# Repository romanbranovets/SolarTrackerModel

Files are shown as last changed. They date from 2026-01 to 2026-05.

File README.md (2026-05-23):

# SolarTrackerModel

Комплексная модель двухосевого солнечного трекера в MATLAB/Simulink с сопутствующей аппаратной частью — блоком управления приводами. Проект объединяет 3D-механику на базе CAD-геометрии, модель электромеханического привода с редуктором, расчёт положения Солнца, ветровые нагрузки и оценку выработанной энергии с учётом точности наведения и потерь в приводах.

Модель собрана модульно: каждый физический аспект вынесен в отдельный `.slx`-файл и подключается в главную схему через Model Reference.

## Демонстрация

Запись симуляции из Mechanics Explorer — слежение за Солнцем, реакция на ветровую нагрузку, изменение ориентации панелей.

Симуляция работы солнечного трекера

## Структура репозитория

```
SolarTrackerModel/
├── Diplomm.m              # параметры привода, редуктора и ветровой модели
├── multibody.slx          # главная интегрированная модель
├── Actuator.slx           # электромеханический привод одной оси
├── regt.slx               # дискретный регулятор
├── MotorEnergyLoss.slx    # расчёт потерь энергии в приводе
├── SolarTrack.slx         # положение Солнца на небе
├── WindGenerator.slx      # ветровая нагрузка
├── EnergyConvert.slx      # расчёт полученной энергии
├── docs/                  # материалы для README
│   └── simulation.gif     # запись симуляции
├── Electronics/           # блок управления приводами
└── 3dmodel/               # CAD-геометрия
```

## Что реализовано

### `multibody.slx` — интегрированная модель

Центральная Simulink-модель, в которой связаны механика, управление и внешние воздействия.

- **Simscape Multibody** — трёхмерная динамика трекера с двумя степенями свободы: азимут и угол места
- **CAD-импорт** — геометрия и инерционные параметры загружаются из STEP-файлов (`3dmodel/`)
- **Два привода** — азимутальный и по углу места, каждый через `Actuator.slx`
- **Внешние воздействия** — солнечная траектория (`SolarTrack.slx`) и ветер (`WindGenerator.slx`)
- **Энергетический баланс** — интеграл полезной выработки с вычетом потерь приводов (`EnergyConvert.slx`)
- **Режимы работы** — автоматическое слежение за Солнцем и ручная подача уставок через переключатели
- **Визуализация** — Scope для углов ориентации и накопленной энергии

Решатель: `ode45`, время моделирования 0–250 с.

### `Actuator.slx` — электромеханический привод

Модель одной оси вращения. Используется дважды — для азимута и угла места.

- **Контур управления** — ошибка по углу, масштабирование и дискретный регулятор `regt.slx` (Ts = 0.01 с)
- **Модель ДПТ** — RL-цепь обмотки, ограничения по напряжению (±24 В) и току (±6.5 А), мёртвая зона «напряжения трогания» (±1.2 В), противо-ЭДС
- **Редуктор** (i = 619) — люфт (dead zone), нелинейное трение, MATLAB Function для определения контакта в зазоре
- **Обратная связь** — угол и скорость с механической части; внешний момент от ветра на входе
- **Выходы** — крутящий момент на шарнир Simscape, напряжение и ток для расчёта потерь

### `regt.slx` — дискретный регулятор

Дискретный компенсатор с периодом дискретизации 0.01 с. Структура — каскад блоков задержки и усиления, полученный в результате дискретизации непрерывной передаточной функции (см. закомментированный код синтеза в `Diplomm.m`).

### `SolarTrack.slx` — положение Солнца

Расчёт углов Солнца для заданного места наблюдения (широта 55°, долгота 37°, часовой пояс UTC+3).

- Склонение Солнца по номеру дня года
- Уравнение времени
- Часовой угол, зенитный угол, высота и азимут
- Ограничение видимости — обнуление угла, когда Солнце ниже горизонта

### `WindGenerator.slx` — ветровая нагрузка

Модель аэродинамического давления на солнечные панели.

- **Скорость ветра** — средняя составляющая, порывы и шум; ограничение 0–25 м/с
- **Направление** — медленные колебания по азимуту и углу места
- **Сила** — пропорциональна квадрату скорости ветра и косинусу угла между ориентацией панели и направлением потока; учитываются габариты панелей (`laz`, `lel`)
- **Выходы** — моменты `MvAz`, `MvEl`, подаваемые на соответствующие приводы

Профиль ветра задокументирован в чертеже `3dmodel/w(t).cdw`.

### `EnergyConvert.slx` — выработанная энергия

Оценка полезной энергии с учётом качества наведения.

- Ошибки ориентации относительно солнечных уставок: `epsAz`, `epsEl`
- КПД наведения: `cos(epsAz) × cos(epsEl)` с пороговым отсечением при больших ошибках
- Номинальная мощность панелей — 400 Вт
- Модель затенения (импульсное снижение освещённости)
- Интеграл: полезная энергия минус потери обоих приводов (`MotorEnergyLoss.slx`)

### `MotorEnergyLoss.slx` — потери в приводе

Расчёт энергозатрат на ориентацию: интеграл `|U · I|` по напряжению и току двигателя.

### `Diplomm.m` — параметры системы

Скрипт инициализации, загружающий в workspace параметры электродвигателя, редуктора и ветровой модели:

| Группа | Параметры |
|---|---|
| Двигатель | `R`, `L`, `Km`, `Kw`, `J`, `Jd` |
| Редуктор | `i`, `c`, `a`, `b`, параметры трения `F1`, `F2`, `G1`, `G2`, `G` |
| Регулятор | `KPDr` |
| Ветер | `laz`, `lel` — характерные размеры панелей |

### `3dmodel/` — CAD-геометрия

Трёхмерная модель механической части трекера.

Основные компоненты: основание, азимутальная рама, солнечные панели, вал, корпус мотора. Сборки включают конфигурации с углом места 0° и 90°.

### `Electronics/` — блок управления

Аппаратная часть системы управления — печатная плата **«Блок управления»** для двухканального управления приводами трекера. Разработка выполнена в Altium Designer; комплект конструкторской документации оформлен по ЕСКД.

**Исходные файлы:**

| Файл | Назначение |
|---|---|
| `main.SchDoc` | принципиальная электрическая схема |
| `PCBGOST.PcbDoc` | топология печатной платы (200×200 мм) |

**Документация (PDF):**

| Файл | Назначение |
|---|---|
| `СхемаЭ3.pdf` | схема электрическая принципиальная (форма Э3) |
| `ПЭ3.pdf` | перечень элементов с пояснениями |
| `Спецификация.pdf` | спецификация на блок управления |
| `СБПДФ.pdf` | сборочный чертёж платы |
| `плата.pdf` | чертёж печатной платы |

**Что реализовано на схеме:**

- **Микроконтроллер STM32F205RGT6** — формирование ШИМ-сигналов управления, UART-интерфейс, опрос датчиков; тактирование от кварца 8 МГц
- **Два силовых канала** — независимое управление приводами азимута и угла места; каждый канал построен на 6 MOSFET-транзисторах `IRFR7740` в трёхполумостовой конфигурации с драйверами `IRS2011`
- **Гальваническая развязка** — 12 оптронов `249ЛП5` в цепях управления затворами; линейные оптопары `IL300` в каналах измерения тока
- **Измерение тока двигателей** — шунты 0.2 Ом, усиление на `LM2904`, гальванически развязанная передача сигналов `I1`/`I2` на АЦП микроконтроллера
- **Система питания** — вход 24 В (разъём `XT30`); DC-DC-преобразователи на шины +15 В, +5 В, +3.3 В для силовой и логической частей
- **Разъёмы** — силовой ввод, UART, JTAG/SWD для отладки, 4 клеммных разъёма Molex для подключения двигателей и периферии

Плата связана с Simulink-моделью через параметры привода из `Diplomm.m` (сопротивление обмотки, ограничения по напряжению и току, передаточное число редуктора) — модель отражает те же электромеханические характеристики, что заложены в аппаратную часть.

## Связи между модулями

```mermaid
flowchart LR
    subgraph Окружение
        ST[SolarTrack]
        WG[WindGenerator]
    end

    subgraph Управление
        ACT[Actuator]
        REG[regt]
        MEL[MotorEnergyLoss]
    end

    subgraph Механика
        MB[multibody]
    end

    subgraph Энергетика
        EC[EnergyConvert]
    end

    ST -->|уставки| ACT
    ST --> EC
    WG -->|моменты| ACT
    ACT --> REG
    ACT -->|момент| MB
    ACT --> MEL
    MB -->|углы, скорости| ACT
    MB -->|углы| WG
    MB -->|углы| EC
    MEL -->|потери| EC
    EC -->|энергия| MB
```

**Поток сигналов:**

1. `SolarTrack` формирует уставки азимута и угла места → `Actuator` (через переключатели режима)
2. `Actuator` выдаёт момент → шарниры Simscape Multibody → углы и скорости обратно в привод
3. `WindGenerator` получает текущую ориентацию и генерирует моменты нагрузки → `Actuator`
4. Углы, солнечные уставки и потери приводов → `EnergyConvert` → интеграл выработанной энергии

## Запуск

**Требования:** MATLAB R2025a (или совместимая версия) с Simulink, Simscape, Simscape Multibody.

1. Открыть проект в MATLAB
2. Выполнить `Diplomm.m` — загрузка параметров в workspace
3. Открыть `multibody.slx` и запустить симуляцию
4. Убедиться, что все Model Reference и STEP-файлы из `3dmodel/` доступны по относительным путям

## Инструменты

| Категория | Инструменты |
|---|---|
| Моделирование | MATLAB / Simulink, Simscape, Simscape Multibody |
| Управление | Дискретный компенсатор, ZOH-дискретизация |
| CAD | SolidWorks, KOMPAS-3D |
| Схемотехника | Altium Designer |

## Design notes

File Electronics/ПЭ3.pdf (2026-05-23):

Изм | Лист | № докум. | Подп. | Дата Инв. № подл. Подп. и дата Инв. № дубл. Взам. инв. № Подп. и дата Перв. Примен. Справ. №
| | | СМ7.000001.001ПЭ3
Разраб. | Брановец | Блок управления Перечень элементов | Лит. | Лист | Листов
Пров. | Романова-Большакова | | | | | 1 5

МГТУ им. Н.Э. Баумана

Поз. обозначен ие | Наименование | Кол. | Примечание
| КОНДЕНСАТОРЫ
С1-C8 | CC0402JRX7R7BB104-0,1мкФ ±15% -16В | 8 | Типоразмер 0402
С9-C10 | CL21B225KAFNNNE-2,2мкФ±15%-25В | 2 | Типоразмер 0805
С11 | CC0603JRNPO8BN150-15пФ±5%-25В | 1 | Типоразмер 0603
С12-С15 | CC0402JRX7R7BB104-0,1мкФ ±15% -16В | 4 | Типоразмер 0402
С16 | EEEFK1H101P-100мкФ±20%-50В | 1
С17 | EEEFK1E220R-22мкФ±20%-25В | 1
С18 | CC0603JRNPO8BN150-15пФ±5%-25В | 1 | Типоразмер 0603
С19 | CL10B104KB8NNNC-0,1мкФ±15% -50В | 1 | Типоразмер 0603
С20 | EEEFK1H101P-100мкФ±20%-50В | 1
С21 | EEEFK1E220R-22мкФ±20%-25В | 1
С22-С27 | CC0402JRX7R7BB104-0,1мкФ ±15% -16В | 6 | Типоразмер 0402
С28-С30 | CL10B104KB8NNNC-0,1мкФ±15% -50В | 3 | Типоразмер 0603
С31-С34 | EEEFK1K220P-22мкФ±20% -80В | 4
С35 | CL10B104KB8NNNC-0,1мкФ±15% -50В | 1 | Типоразмер 0603
С36 | CC0402JRX7R7BB104-0,1мкФ ±15% -16В | 1 | Типоразмер 0402
С37-С39 | CL10B104KB8NNNC-0,1мкФ±15% -50В | 3 | Типоразмер 0603
С40 | CC0402JRX7R7BB104-0,1мкФ ±15% -16В | 1 | Типоразмер 0402
С41 | CL10B104KB8NNNC-0,1мкФ±15% -50В | 1 | Типоразмер 0603
С42 | CL32B225KCJSNNE-2,2мкФ±15%-100В | 1 | Типоразмер 1210
С43-С44 | CC0402JRX7R7BB104-0,1мкФ ±15% -16В | 2 | Типоразмер 0402
С45 | CL10B104KB8NNNC-0,1мкФ±15% -50В | 1 | Типоразмер 0603
С46 | CC0402JRX7R7BB104-0,1мкФ ±15% -16В | 1 | Типоразмер 0402
С47 | CL32B225KCJSNNE-2,2мкФ±15%-100В | 1 | Типоразмер 1210
С48 | CL10B104KB8NNNC-0,1мкФ±15% -50В | 1 | Типоразмер 0603
С49 | CC0402JRX7R7BB104-0,1мкФ ±15% -16В | 1 | Типоразмер 0402

СМ7.000001.001ПЭ3
2

Лист Инв. № подл.

С50-С53 | CL10B104KB8NNNC-0,1мкФ±15% -50В | 4 | Типоразмер 0603
С54-С55 | CC0402JRX7R7BB104-0,1мкФ ±15% -16В | 2 | Типоразмер 0402

МИКРОСХЕМЫ

DA1 | UWF1205S-3WR3 | 1 | DC-DC преобразователь
DA2 | IRS2011SPbf | 1 | Драйвер полумоста
DA3 | UWF1205S-3WR3 | 1 | DC-DC преобразователь
DA4-DA6 | SN74LVC2G17 | 3 | Буфер
DA7 | AM2S-2415SZ | 1 | DC-DC преобразователь
DA8-DA11 | SN74LVC2G17 | 4 | Буфер
DA12 | AM2S-2403SZ | 1 | DC-DC преобразователь
DA13 | IRS2011SPbf | 1 | Драйвер полумоста
DA14 | SN74LVC2G17 | 1 | DC-DC преобразователь
DA15 | IL300 | 1 | Линейная оптопара
DA16 | IRS2011SPbf | 1 | Драйвер полумоста
DA17 | LM2904DR2G | 1 | Операционный усилитель
| | DA18 | SN74LVC2G17 | 1 | Буфер
| | DA19 | IL300 | 1 | Линейная оптопара
| | DA20 | SN74LVC2G17 | 1 | Буфер
| | DA21 | IL300 | 1 | Линейная оптопара
| | DA22 | LM2904DR2G | 1 | Операционный усилитель
| | DA23 | IRS2011SPbf | 1 | Драйвер полумоста
| | DA24 | SN74LVC2G17 | 1 | Буфер
| | Изм Лист DA25 | № докум. Подп. Дата Подп. и дата Взам. инв.№ Инв. № дубл. Подп. и дата IL300 | 1 | Линейная оптопара
| | DA26 | LM2904DR2G | 1 | Операционный усилитель
| | DA27 | SN74LVC2G17 | 1 | Буфер
| | DA28- | IRS2011SPbf | 2 | Драйвер полумоста
| | DA29
| | DA30- | SN74LVC2G17 | 2 | Драйвер полумоста
| | DA31
| | DD1-DD8 | 249ЛП5 | 8 | Оптрон
| | DD9 | STM32F205RGT6 | 1 | Микроконтроллер
| | DD10-DD13 | 249ЛП5 | 4 | Оптрон

3

Резисторы Р1-12 | ШКАБ.434110.002 ТУ
R1-R4 | Р1-12-0,125-340 Ом ±1% - М | 4
R5-R8 | Р1-12-0,125-169 Ом ±1% - М | 4
R9-R11 | Р1-12-0,062-20 кОм ±5% - М | 3
R12-R15 | Р1-12-0,125-340 Ом ±1% - М | 4
R16-R17 | Р1-12-0,062-20 кОм ±5% - М | 2
R18-R21 | Р1-12-0,125-169 Ом ±1% - М | 4
R22-R26 | Р1-12-0,062-20 кОм ±5% - М | 5
R27-R30 | Р1-12-0,125-340 Ом ±1% - М | 4
R31 | Р1-12-0,062-20 кОм ±5% - М | 1
R32-R35 | Р1-12-0,125-169 Ом ±1% - М | 4
R36 | Р1-12-0,062-20 кОм ±5% - М | 1
R37 | Р1-12-0,062-680 Ом ±1% - М | 1
R38 | Р1-12-0,125-10 кОм ±5% - М | 1
R39 | Р1-12-0,062-10 кОм ±5% - М | 1
R40-R41 | Р1-12-0,125-15 Ом ±1% - М | 2
| | R42 | Р1-12-0,125-10 кОм ±5% - М | 1
| | R43-R44 | Р1-12-0,062-10 кОм ±5% - М | 2
| | R45 | Р1-12-0,125-10 кОм ±5% - М | 1
| | R46-R47 | Р1-12-0,125-15 Ом ±1% - М | 2
| | R48-R49 | Р1-12-0,125-10 кОм ±5% - М | 2
| | R50 | Р1-12-0,062-1.2 кОм ±1% - М | 1
| | R51 | Р1-12-0,125-15 Ом ±1% - М | 1
| | Изм Лист R52 | № докум. Подп. Дата Подп. и дата Взам. инв.№ Инв. № дубл. Подп. и дата Р1-12-0,062-20 кОм ±5% - М | 1
| | R53 | Р1-12-0,125-15 Ом ±1% - М | 1
| | R54 | Р1-12-0,062-47 кОм ±1% - М | 1
| | R55 | Р1-12-0,062-20 кОм ±5% - М | 1
| | R56 | Р1-12-0,125-10 кОм ±5% - М | 1
| | R57 | Р1-12-0,062-1.2 кОм ±1% - М | 1
| | R58 | Р1-12-0,062-20 кОм ±5% - М | 1
| | R59-R62 | WSR3R2000FEA-3Вт-0,2 Ом ±1% | 4
| | R63 | Р1-12-0,062-47 кОм ±1% - М | 1
| | R64 | Р1-12-0,062-20 кОм ±5% - М | 1

4

R65 | Р1-12-0,062-620 кОм ±5% - М | 1
R66 | Р1-12-0,125-10 кОм ±5% - М | 1
R67 | Р1-12-0,062-1.2 кОм ±1% - М | 1
R68 | Р1-12-0,125-15 Ом ±1% - М | 1
R69-R70 | Р1-12-0,062-20 кОм ±5% - М | 2
R71 | Р1-12-0,125-15 Ом ±1% - М | 1
R72 | Р1-12-0,062-47 кОм ±1% - М | 1
R73 | Р1-12-0,125-10 кОм ±5% - М | 1
R74 | Р1-12-0,062-620 кОм ±5% - М | 1
R75 | Р1-12-0,062-1.2 кОм ±1% - М | 1
R76 | Р1-12-0,062-20 кОм ±5% - М | 1
R77 | Р1-12-0,062-47 кОм ±1% - М | 1
R78 | Р1-12-0,062-20 кОм ±5% - М | 1
R79 | Р1-12-0,125-10 кОм ±5% - М | 1
R80 | Р1-12-0,062-18 кОм ±1% - М | 1
R81 | Р1-12-0,125-15 Ом ±1% - М | 1
R82 | Р1-12-0,062-10 кОм ±5% - М | 1
| | R83 | Р1-12-0,125-95,3 Ом ±1% - М | 1
| | R84-R87 | WSR3R2000FEA-3Вт-0,2 Ом ±1% - М | 4
| | R88 | Р1-12-0,125-15 Ом ±1% - М | 1
| | R89 | Р1-12-0,125-95,3 Ом ±1% - М | 1
| | R90 | Р1-12-0,125-95,3 Ом ±1% - М | 1
| | R91 | Р1-12-0,125-10 кОм ±5% - М | 1
| | R92 | Р1-12-0,062-18 кОм ±1% - М | 1
| | Изм Лист R93 | № докум. Подп. Дата Подп. и дата Взам. инв.№ Инв. № дубл. Подп. и дата Р1-12-0,125-95,3 Ом ±1% - М | 1
| | R94 | Р1-12-0,062-10 кОм ±5% - М | 1
| | R95-R96 | Р1-12-0,125-95,3 Ом ±1% - М | 2
| | R97 | Р1-12-0,062-1 кОм ±5% - М | 1
| | R98 | Р1-12-0,125-10 кОм ±5% - М | 1
| | R99 | Р1-12-0,062-1 кОм ±5% - М | 1
| | R100 | Р1-12-0,125-15 Ом ±1% - М | 1
| | R101 | Р1-12-0,062-1 кОм ±5% - М | 1
| | R102 | Р1-12-0,125-15 Ом ±1% - М | 1
| | R103 | Р1-12-0,125-10 кОм ±5% - М | 1

5

ДИОДЫ

VD1-VD2 | DFLS160-7-60В-1А | 2
VD3-VD4 | VS-8TQ100S-M3-100В-8А | 2
VD5-VD8 | DFLS160-7-60В-1А | 4

ТРАНЗИСТОРЫ

VT1- | IRFR7740PbF-75В-87А | 12
VT12

ДРОССЕЛИ

L1-L2 | IHLP-6767GZ-01-15мкГн±30%-25А | 2
L3-L8 | IHLP-6767GZ-11-100мкГн±30%-10А | 6

КВАРЦЕВЫЕ РЕЗОНАТОРЫ

ZQ1 | ABM3-8.000МГц-D2Y-T | 1

СОЕДИНИТЕЛИ

X1 | Molex-22-27-2041 | 1
X2-X5 | Molex-430452009 | 4
Изм Лист X6 | № докум. Подп. Дата Подп. и дата Взам. инв.№ Инв. № дубл. Подп. и дата XT30U-F | 1

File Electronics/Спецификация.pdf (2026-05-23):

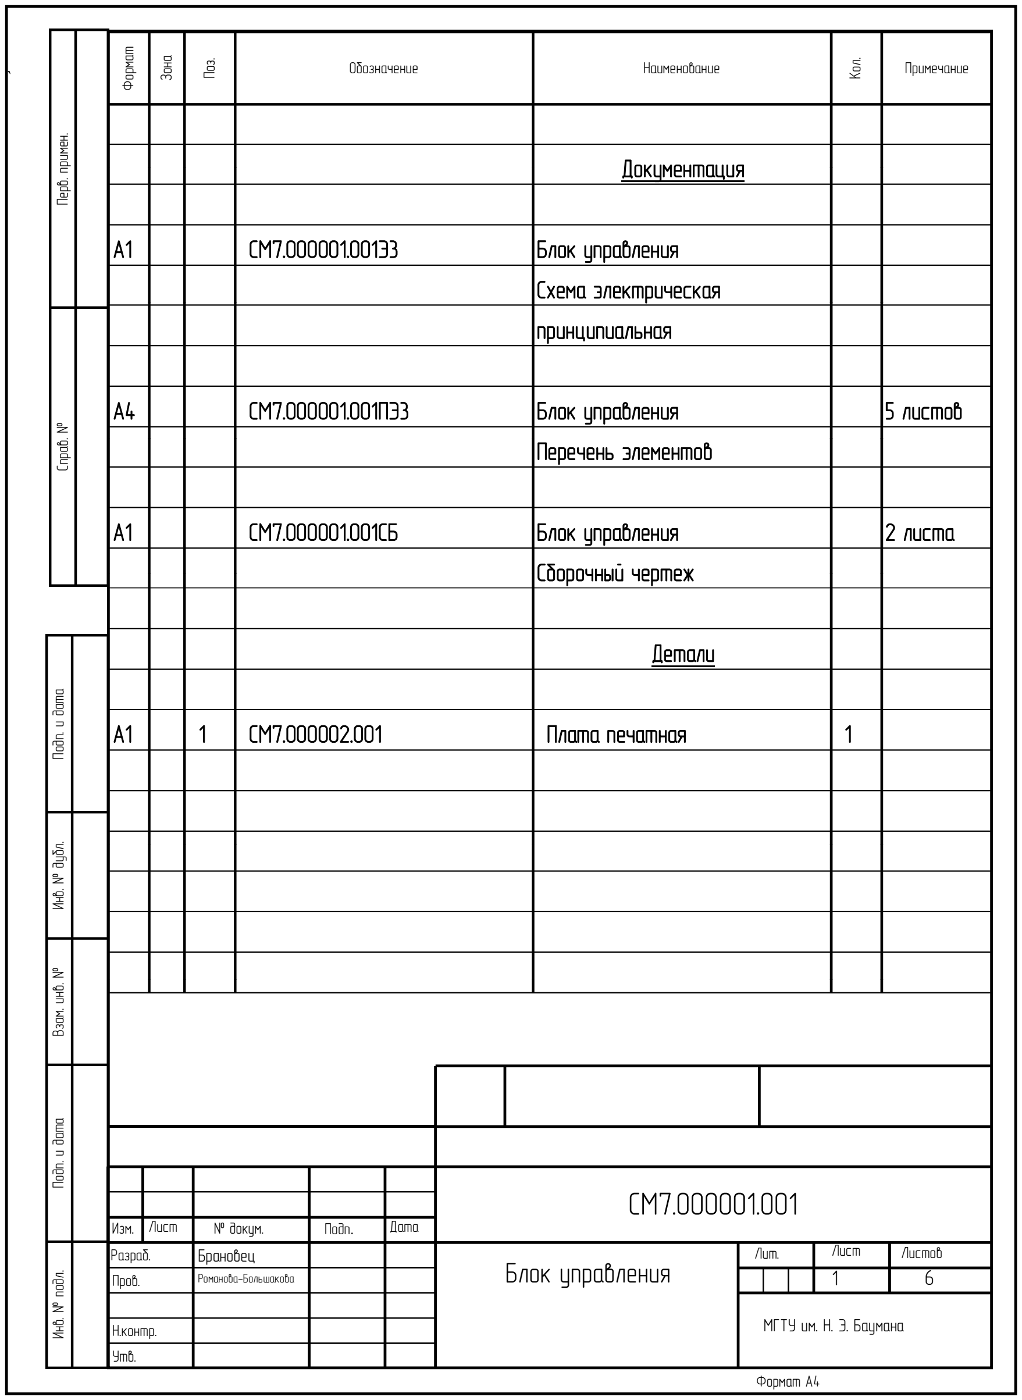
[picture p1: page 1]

Формат Зона Поз. Обозначение Наименование Кол. Примечание

Перв. примен. Справ. № Подп. и дата Инв. № дубл. Взам. инв. № Подп. и дата Инв. № подл.

Формат А4

СМ7.000001.001

Изм. | Лист | № докум. | Подп. | Дата
Разраб. | | Блок управления Брановец
Пров. | Романова-Большакова

Н.контр.
Утв.
Лит. | Лист | Листов
1 6

`

МГТУ им. Н. Э. Баумана

Документация

А1 | | СМ7.000001.001Э3 | Блок управления Схема электрическая принципиальная
А4 | СМ7.000001.001ПЭ3 | Блок управления | 5 листов
| | | Перечень элементов
А1 | СМ7.000001.001СБ | Блок управления | 2 листа
| | | Сборочный чертеж
| | | Детали
А1 | 1 | СМ7.000002.001 | Плата печатная | 1

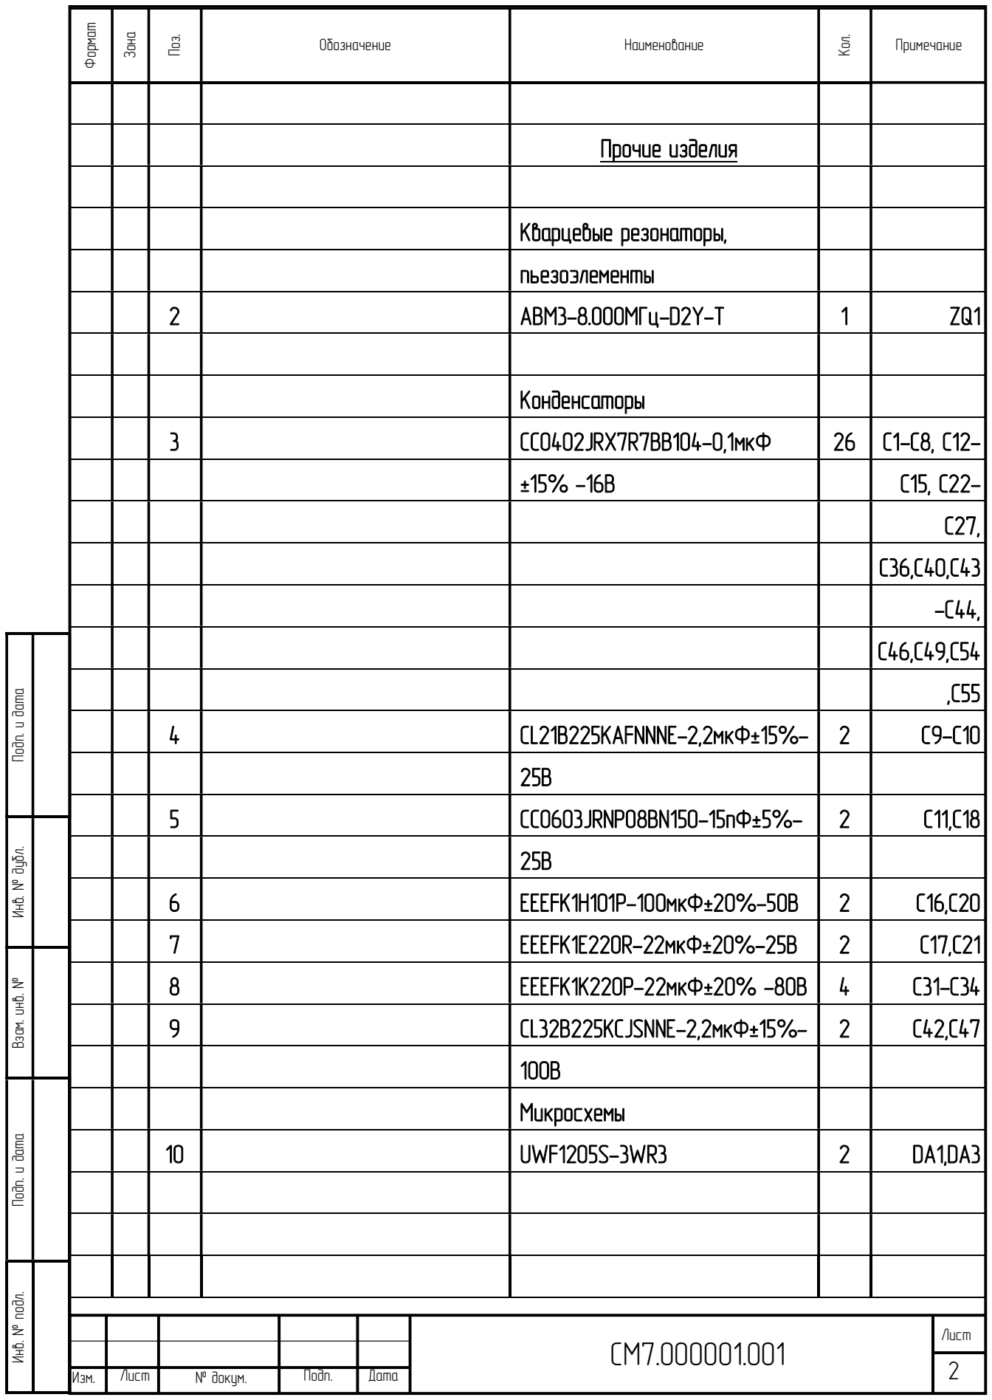
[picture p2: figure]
№ докум.; Подп.; Лист; Изм.; Дата; Прочие изделия; Кварцевые резонаторы,; пьезоэлементы; ABM3-8.000МГц-D2Y-T; Конденсаторы; 3 CC0402JRX7R7BB104-0,1мкФ; 4 CL21B225KAFNNNE-2,2мкФ±15%-; 5 CC0603JRNPO8BN150-15пФ±5%-; EEEFK1H101P-100мкФ±20%-50В; EEEFK1E220R-22мкФ±20%-25В; EEEFK1K220P-22мкФ±20% -80В; 9 CL32B225KCJSNNE-2,2мкФ±15%-; Микросхемы; UWF1205S-3WR3

Подп. и дата Инв. № дубл. Взам. инв. № Подп. и дата Инв. № подл.

Подп. и дата Инв. № дубл. Взам. инв. № Подп. и дата Инв. № подл.

СМ7.000001.001
№ докум. | Подп.

Лист

Изм. | Лист | Дата | 3
11 | IRS2011SPbf | 6 | DA2,DA13
| | | DA16,
| | | DA23,
| | | DA28, DA29
12 | SN74LVC2G17 | 14 | DA4-DA6,
| | | DA8-DA11,
| | | DA14, DA18,
| | | DA20,
| | | DA24,
| | | DA27,
| | | DA30, DA31
13 | AM2S-2415SZ | 1 | DA7
14 | AM2S-2403SZ | 1 | DA12
15 | IL300 | 4 | DA15, DA19,
| | | DA21, DA25
16 | LM2904DR2G | 3 | DA17, DA22,
| | | DA26
17 | 249ЛП5 | 12 | DD1-DD8,
| | | DD10-DD13
18 | STM32F205RGT6 | 1 | DD9
| Катушки индуктивности

### 19 IHLP-6767GZ-01-15мкГн±30%-

| 25А

### 2 L1,L2

### 20 IHLP-6767GZ-11-100мкГн±30%-

| 10А

### 6 L3-L8

Подп. и дата Инв. № дубл. Взам. инв. № Подп. и дата Инв. № подл.

СМ7.000001.001
№ докум. | Подп.

Лист

Изм. | Лист | Дата | 4

Резисторы
21 | Р1-12-0,125-340 Ом ±1% | 12 | R1-R4,
| | | R12-R15,
| | | R27-R30
22 | Р1-12-0,125-169 Ом ±1% | 12 | R5-R8,
| | | R18-R21,
| | | R32-R35
23 | Р1-12-0,062-20 кОм ±5% | 20 | R9-R11,
| | | R16,R17,
| | | R22-R26,
| | | R31, R36,
| | | R52, R55,
| | | R58, R64,
| | | R69, R70,
| | | R76, R78
24 | Р1-12-0,062-680 Ом ±1% | 1 | R37
25 | Р1-12-0,125-10 кОм ±5% | 12 | R38, R42,
| | | R45, R48,
| | | R49, R56,
| | | R66, R73,
| | | R79, R91,
| | | R98, R103
26 | Р1-12-0,062-10 кОм ±5% | 5 | R39, R43,
| | | R44, R82,
| | | R94

Подп. и дата Инв. № дубл. Взам. инв. № Подп. и дата Инв. № подл.

СМ7.000001.001
№ докум. | Подп.

Лист

Изм. | Лист | Дата | 5
27 | Р1-12-0,125-15 Ом ±1% | 12 | R40, R41,
| | | R46, R47,
| | | R51, R53,
| | | R68, R71,
| | | R81, R88,
| | | R100,
| | | R102
28 | Р1-12-0,062-1.27 кОм ±1% | 4 | R50, R57,
| | | R67, R75
29 | Р1-12-0,062-47 кОм ±1% | 4 | R54,R63
| | | R72,R77
30 | WSR3R2000FEA-3Вт-0,2 Ом±1% | 8 | R59-R62,
| | | R84-R87
31 | Р1-12-0,062-620 кОм ±5% | 2 | R65, R74
32 | Р1-12-0,062-18 кОм ±1% | 2 | R80, R92
33 | Р1-12-0,125-95,3 Ом ±1% | 6 | R83, R89,
| | | R90, R93,
| | | R95, R96
34 | Р1-12-0,062-1 кОм ±5% | 3 | R97, R99,
| | | R101

Диоды
35 | DFLS160-7-60В-1А | 6 | VD1, VD2
| | | VD5-VD8

Подп. и дата Инв. № дубл. Взам. инв. № Подп. и дата Инв. № подл.

СМ7.000001.001
№ докум. | Подп.

Лист

Изм. | Лист | Дата | 6
36 | VS-8TQ100S-M3-100В-8А | 2 | VD3, VD4
| Транзисторы
37 | IRFR7740PbF-75В-87А | 12 | VT1-VT12
| Соединители
38 | Molex-22-27-2041 | 1 | Х1
39 | Molex-430452009 | 4 | Х2-Х5
40 | XT30U-F | 1 | Х6

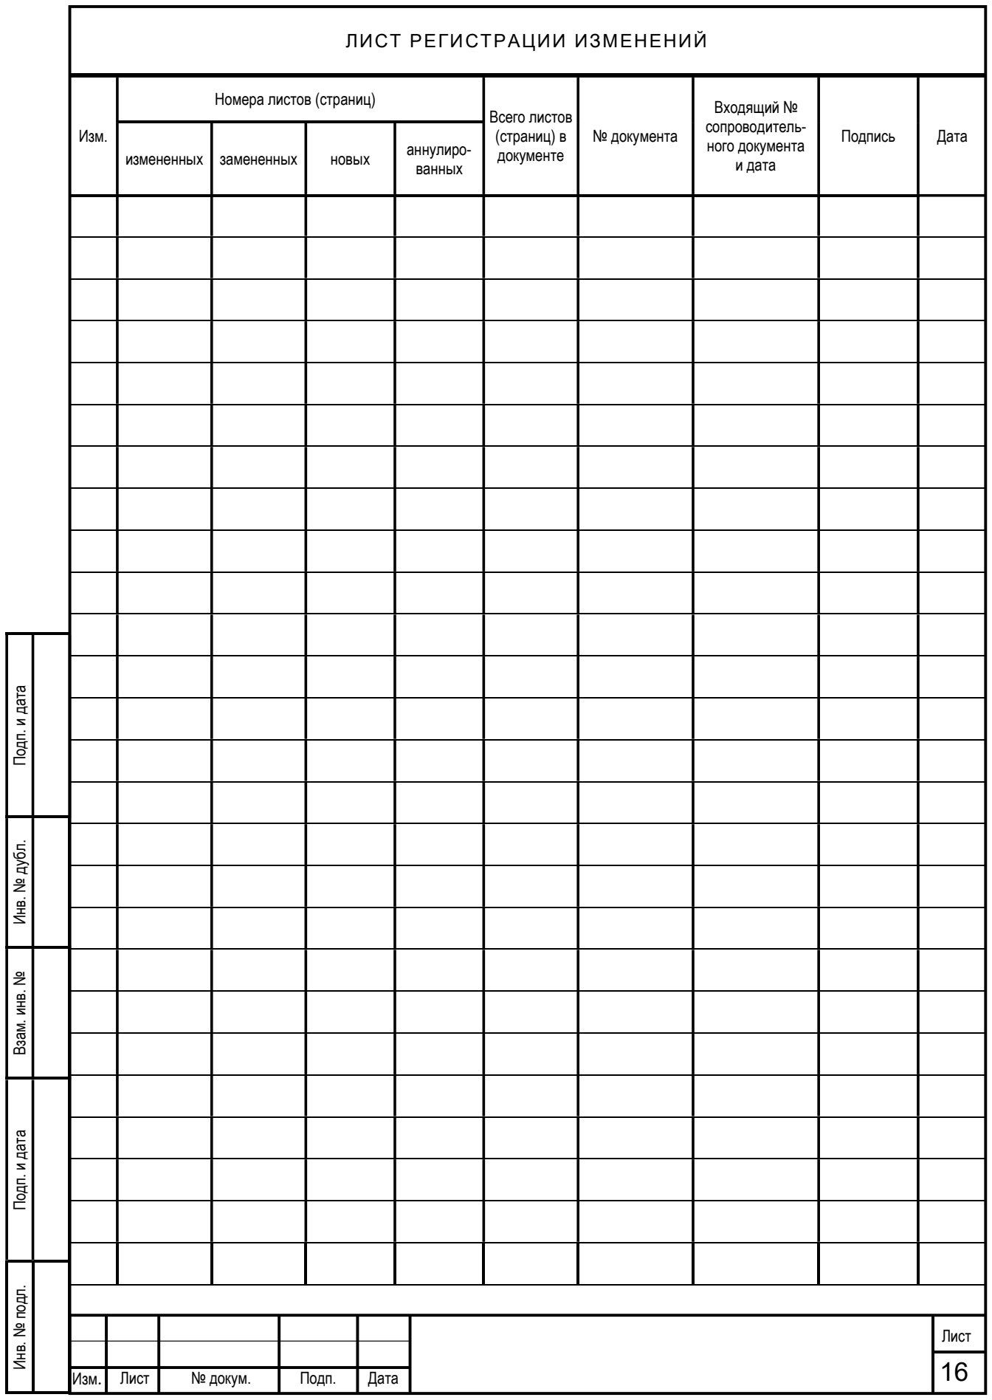
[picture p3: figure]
ЛИСТ РЕГИСТРАЦИИ ИЗМЕНЕНИЙ; Изм.; Номера листов (страниц); Всего листов (страниц) в документе; № документа; Входящий № сопроводитель- ного документа и дата; Подпись; Дата; измененных; замененных; новых; аннулиро- ванных; Лист; № докум.; Подп.; Лист 16

Подп. и дата Инв. № дубл. Взам. инв. № Подп. и дата Инв. № подл.

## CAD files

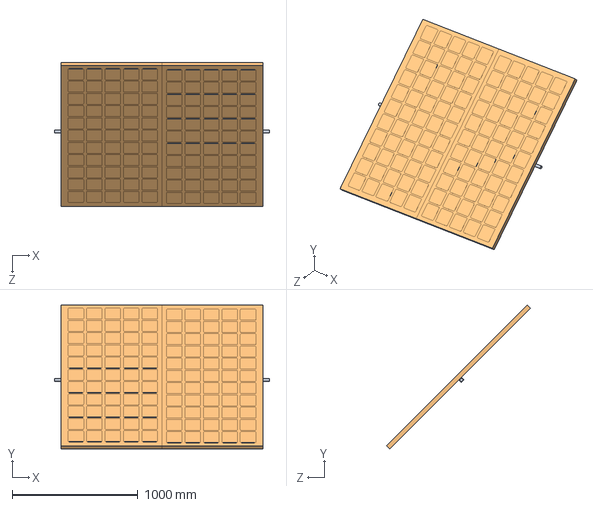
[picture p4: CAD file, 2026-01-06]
3dmodel/сборка с рамой.SLDASM
1712.0 x 1146.2 x 1146.2 mm
Солнечная панель x 2
вал

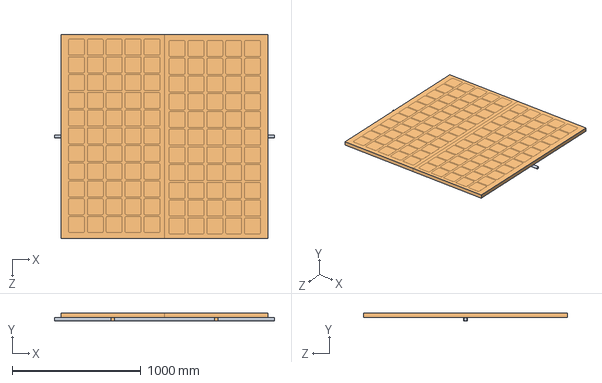
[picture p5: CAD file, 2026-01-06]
3dmodel/угол места 90.SLDASM
1712.0 x 65.5 x 1586.0 mm
Солнечная панель x 2
вал

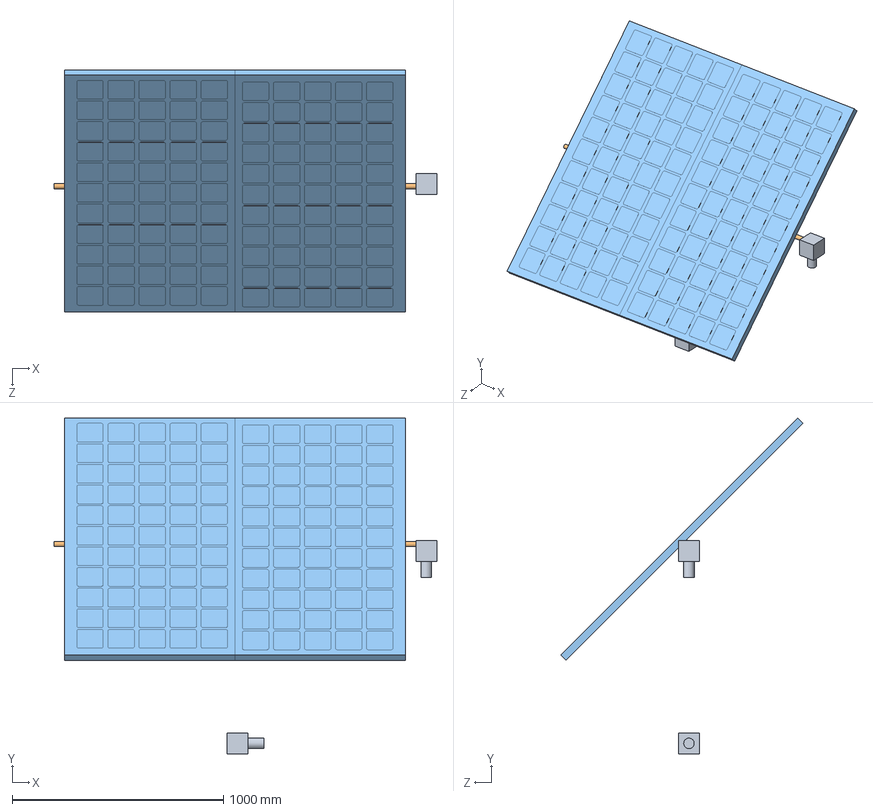
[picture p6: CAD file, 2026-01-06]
3dmodel/общая сборка.SLDASM
1812.0 x 1589.1 x 1146.2 mm
Солнечная панель x 2
вал
мотор x 2

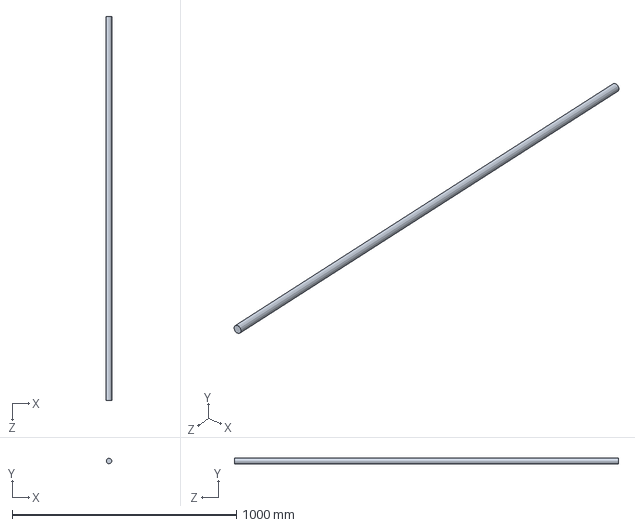
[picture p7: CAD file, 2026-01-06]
3dmodel/вал.SLDPRT
25.0 x 24.8 x 1712.0 mm

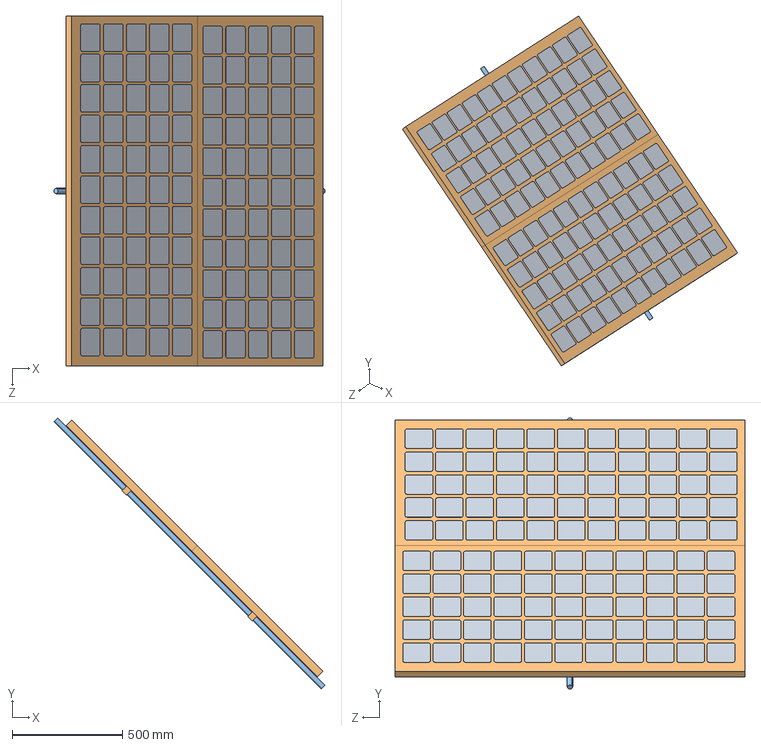
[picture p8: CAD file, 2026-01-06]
3dmodel/сборкасбласт.STEP
1228.2 x 1228.2 x 1586.0 mm

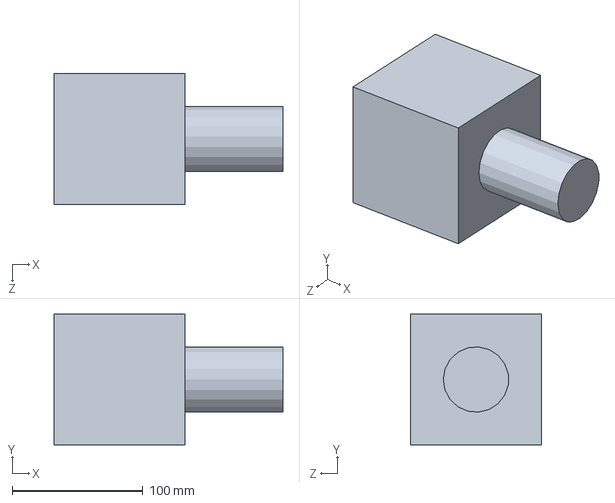
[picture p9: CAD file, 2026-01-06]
3dmodel/мотор.SLDPRT
175.0 x 100.0 x 100.0 mm

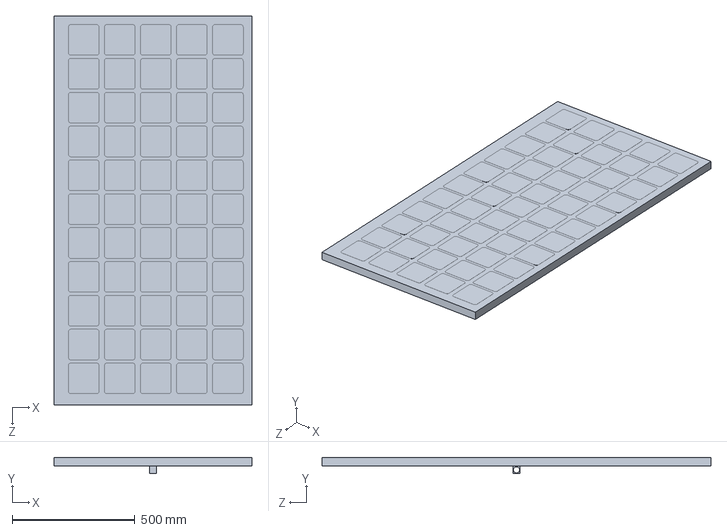
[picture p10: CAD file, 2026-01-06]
3dmodel/Солнечная панель.SLDPRT
806.0 x 65.5 x 1586.0 mm

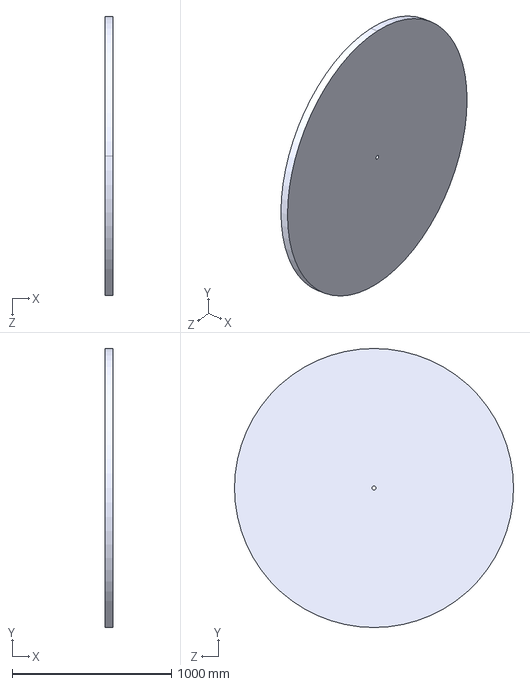
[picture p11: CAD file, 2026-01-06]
3dmodel/основание.STEP
50.0 x 1750.0 x 1750.0 mm

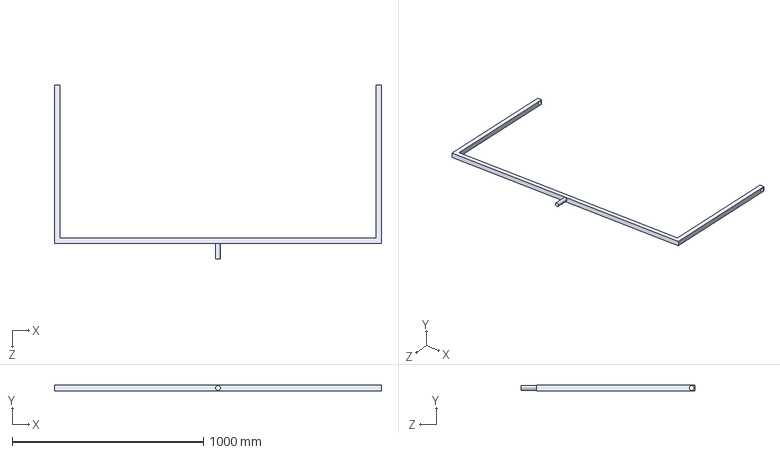
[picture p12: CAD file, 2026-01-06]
3dmodel/Рама.STEP
1712.0 x 30.0 x 910.0 mm

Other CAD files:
3dmodel/угол места 0.SLDASM
3dmodel/sborkasb.STEP
3dmodel/сборка сб.STEP
3dmodel/sborkasbdet.STEP
3dmodel/сборка сб часть.SLDPRT
3dmodel/sborkasp.STEP
3dmodel/Рама.SLDPRT
3dmodel/основание.SLDPRT
3dmodel/сборка сб.SLDASM
3dmodel/сборкасбласт.SLDPRT

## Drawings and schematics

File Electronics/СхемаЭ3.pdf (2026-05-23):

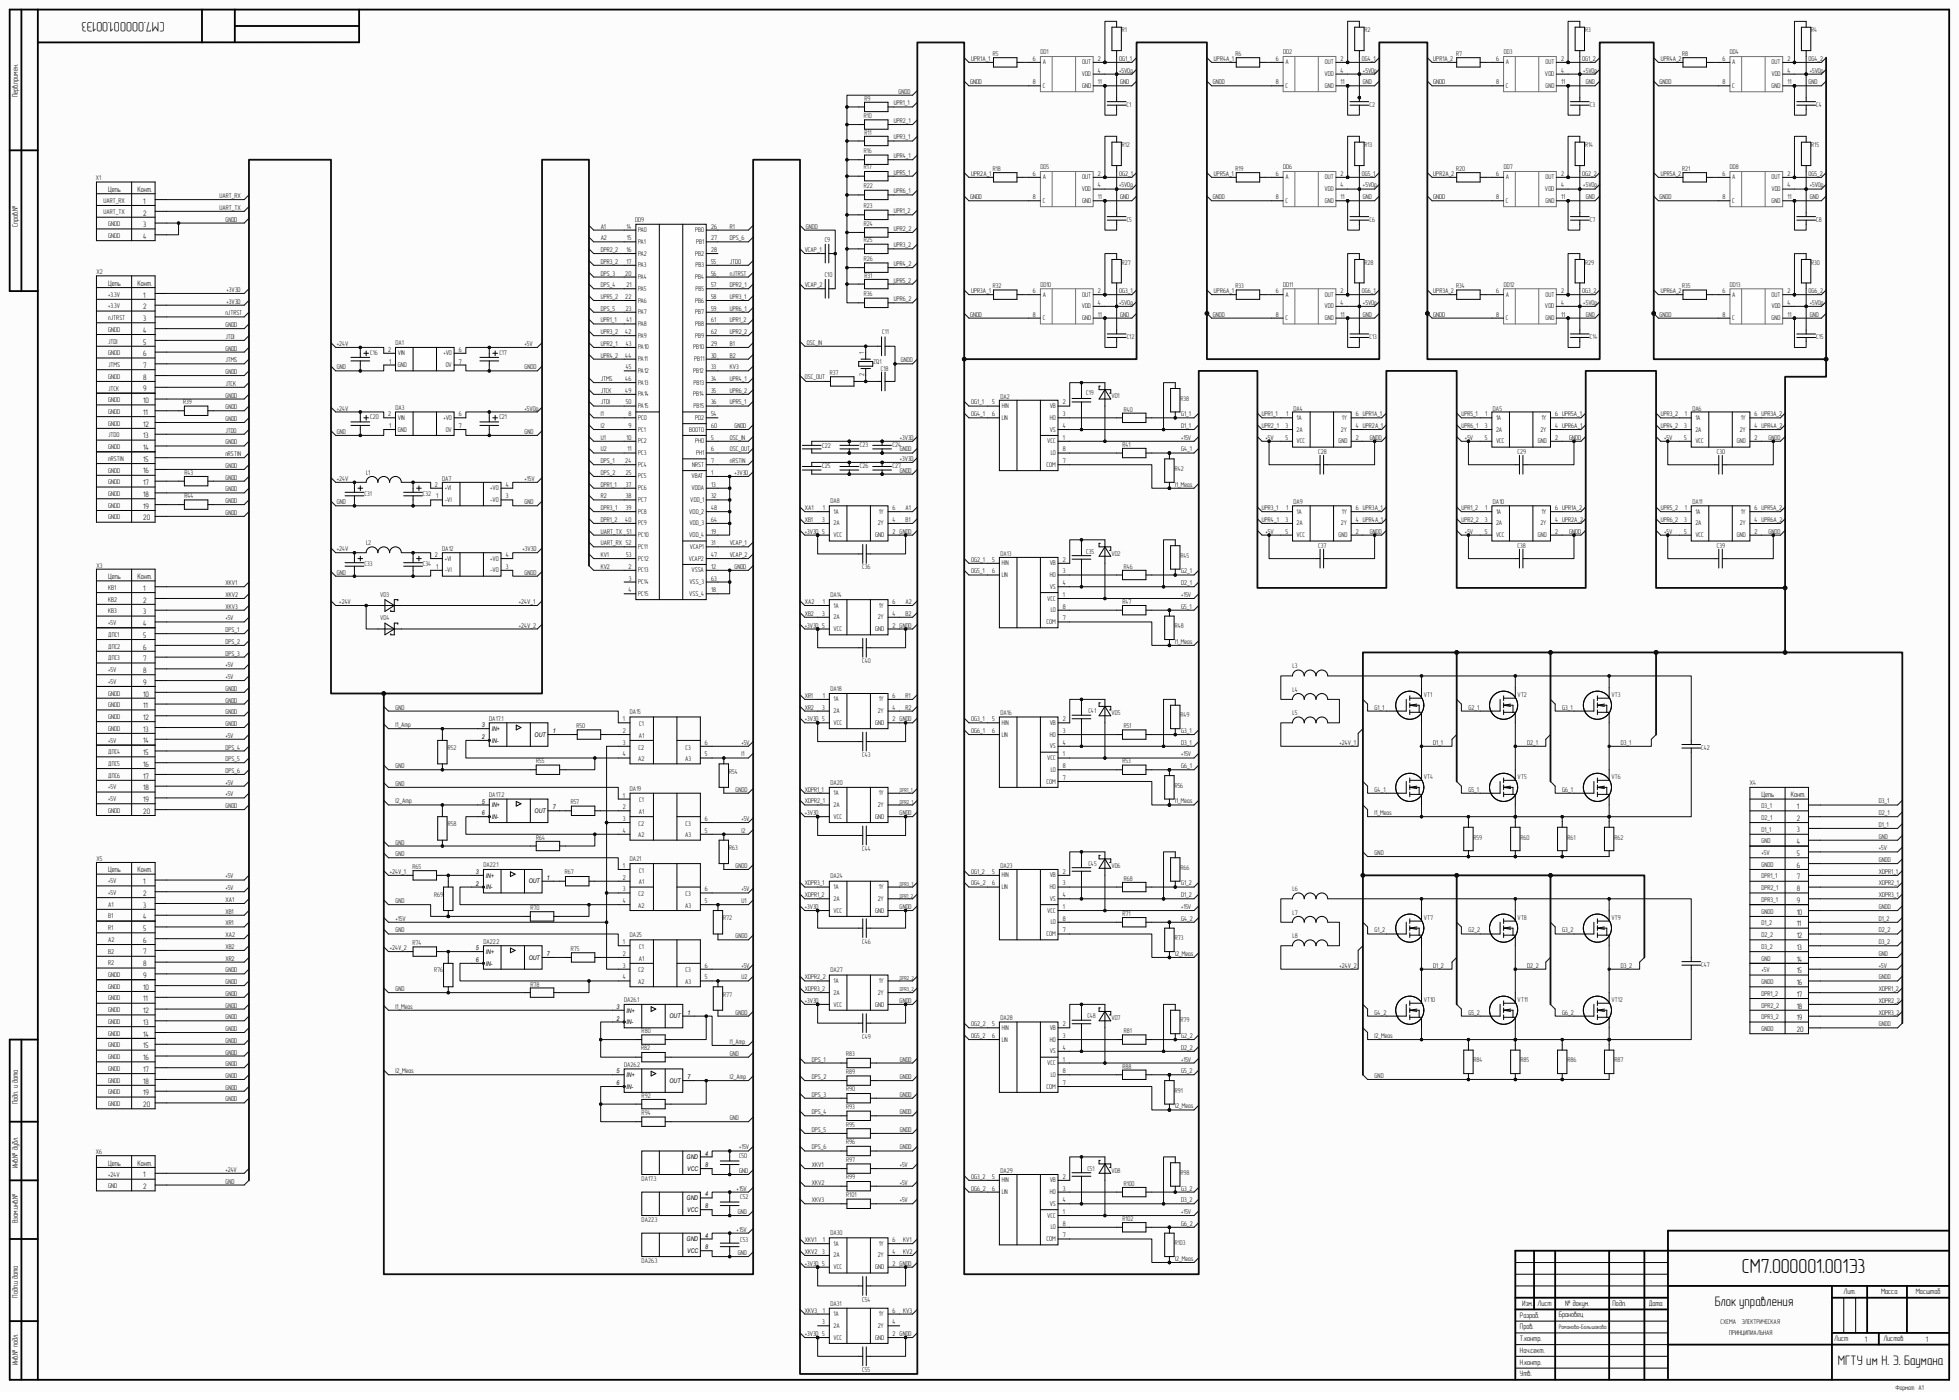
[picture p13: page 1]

Инв.№ подл. Подп.и дата Взам.инв.№ Инв.№ дубл. Подп. и дата Справ.№ Перв.примен.

Цепь UART_RX | Конт. 1234

UART_TX

GNDD
JTDI
JTCK | 146789
JTMS

GNDD | 10
GNDD | 11

nRSTIN | 15
GNDD | 16
GNDD | 17
GNDD | 18 | | 1
GNDD | 19

Цепь КВ2 | Конт. 12345
КВ1

ДПС1
ДПС2
+5V | 146789
ДПС3
+5V

D1_1
GND

DPR1_1

GNDD | 146789
A2
B2

GNDD | 12
GNDD | 13

Цепь +24V | Конт. 12

Блок управления СХЕМА ЭЛЕКТРИЧЕСКАЯ ПРИНЦИПИАЛЬНАЯ | Лит. | Масса | Масштаб

Изм. | Лист | № докум. | Подп. | Дата
Разраб. | | Брановец
Пров. | | Романова-Большакова
Т.контр. | | | | | Лист 1 | Листов 1
Нач.сект. | | | | | МГТУ им Н. Э. Баумана
Н.контр.
Утв.

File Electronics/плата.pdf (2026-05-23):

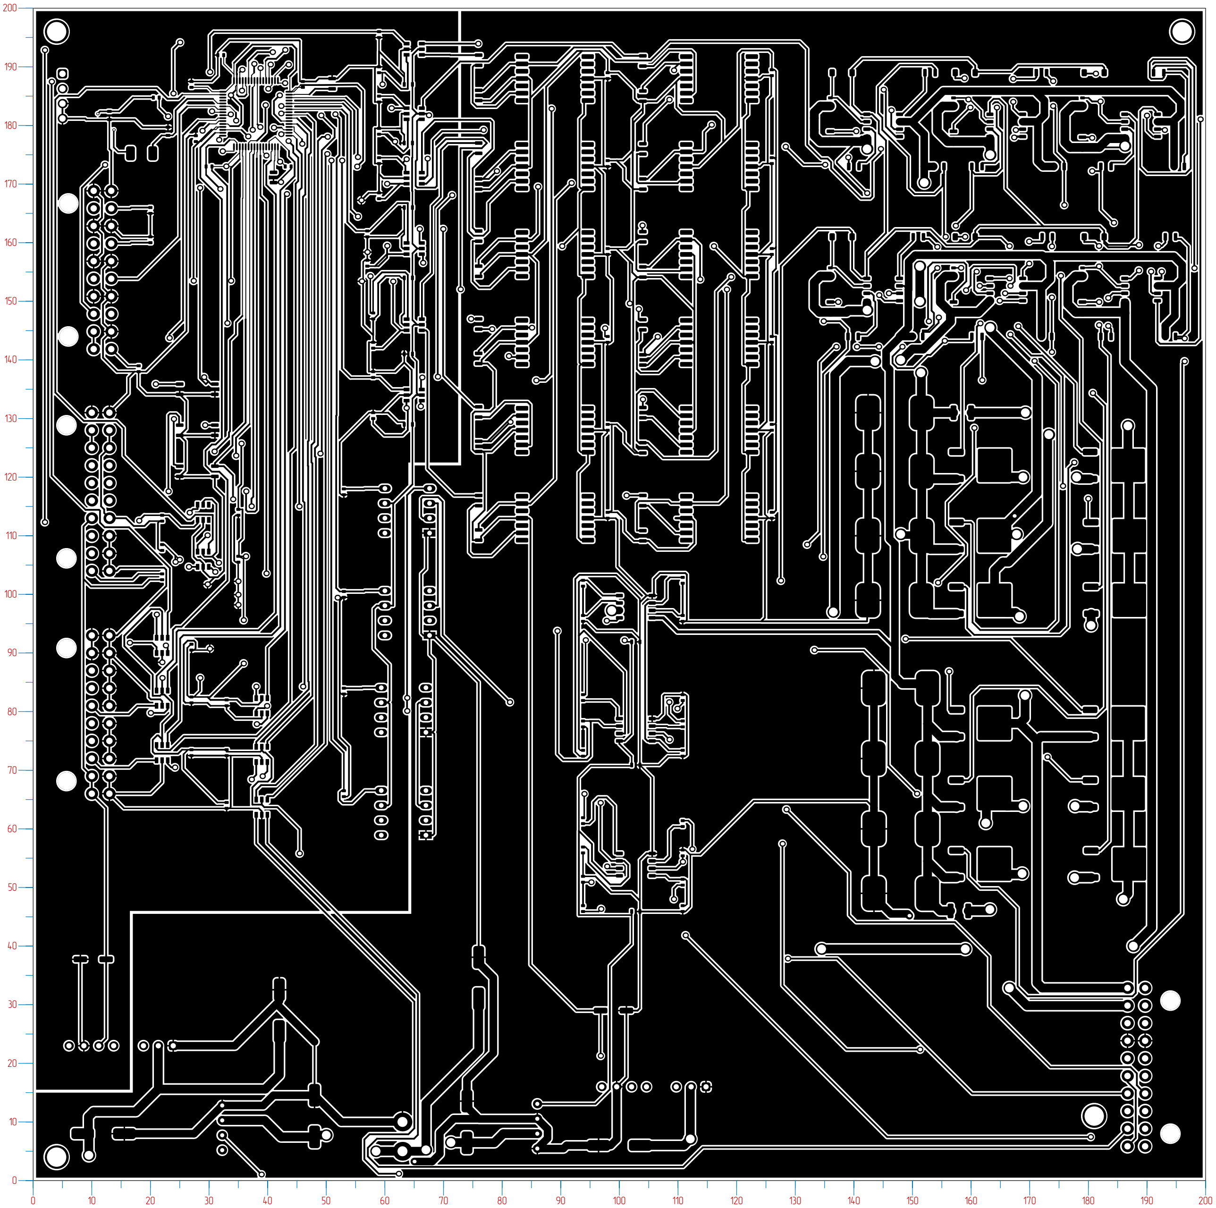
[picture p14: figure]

0 | 10 | 20 | 30 | 40 | 50 | 60 | 70 | 80 | 90 | 100 | 110 | 120 | 130 | 140 | 150 | 160 | 170 | 180 | 190 | 200

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
Усл. обозн. Количество 2

2728

32
14
84
41284

Диаметр отверстия, мм
0.30
0.60
0.70
0.80
0.90
1.10
1.50
1.70
3.00
3.30

Таблица 1
Металлизация
Есть
Есть
Есть
Есть
Есть
Есть
Есть
Есть
Есть
Нет

Условное обозначение

Толщина
проводника, мм
0,15
0,25
0,3
0,4
1,3
1,5

Таблица 2

1. *Размеры для справок
2. Информация о порядке следования слоев печатной платы приведена на виде А-А, структура слоёв в таблице 3

### 3. Печатная плата должна соответствовать ГОСТ 23752-79, группа жесткости 4

### 4. Плату изготовить субстрактивным методом

### 5. Информация об обозначениях и размерах отверстий на виде Б в таблице 1

### 6. Шаг координатной сетки 0,2 мм. Линии координатной сетки не нанесены

7. Покрытие печатной платы защитной жидкости паяльной маской класса требования по ГОСТ Р 54849-2011
8. Маркировать обозначения элементов согласно ГОСТ 25486-82 шрифтом 2,5 тип А ГОСТ 2.304-81

### 9. Расстояние между печатными прободниками не менее 0,15 мм

### 10. Ширина проводников не менее 0,15 мм

11. Отступ элементов от неметаллизированных отверстий и края печатной платы не менее 0,25 мм

### 12. Информация об обозначениях и ширинах проводников приведена в таблице 2

### 13. Остальные технические требования по ОСТ 4Г 0.070.015

Технические требования

Rz40

Rz40

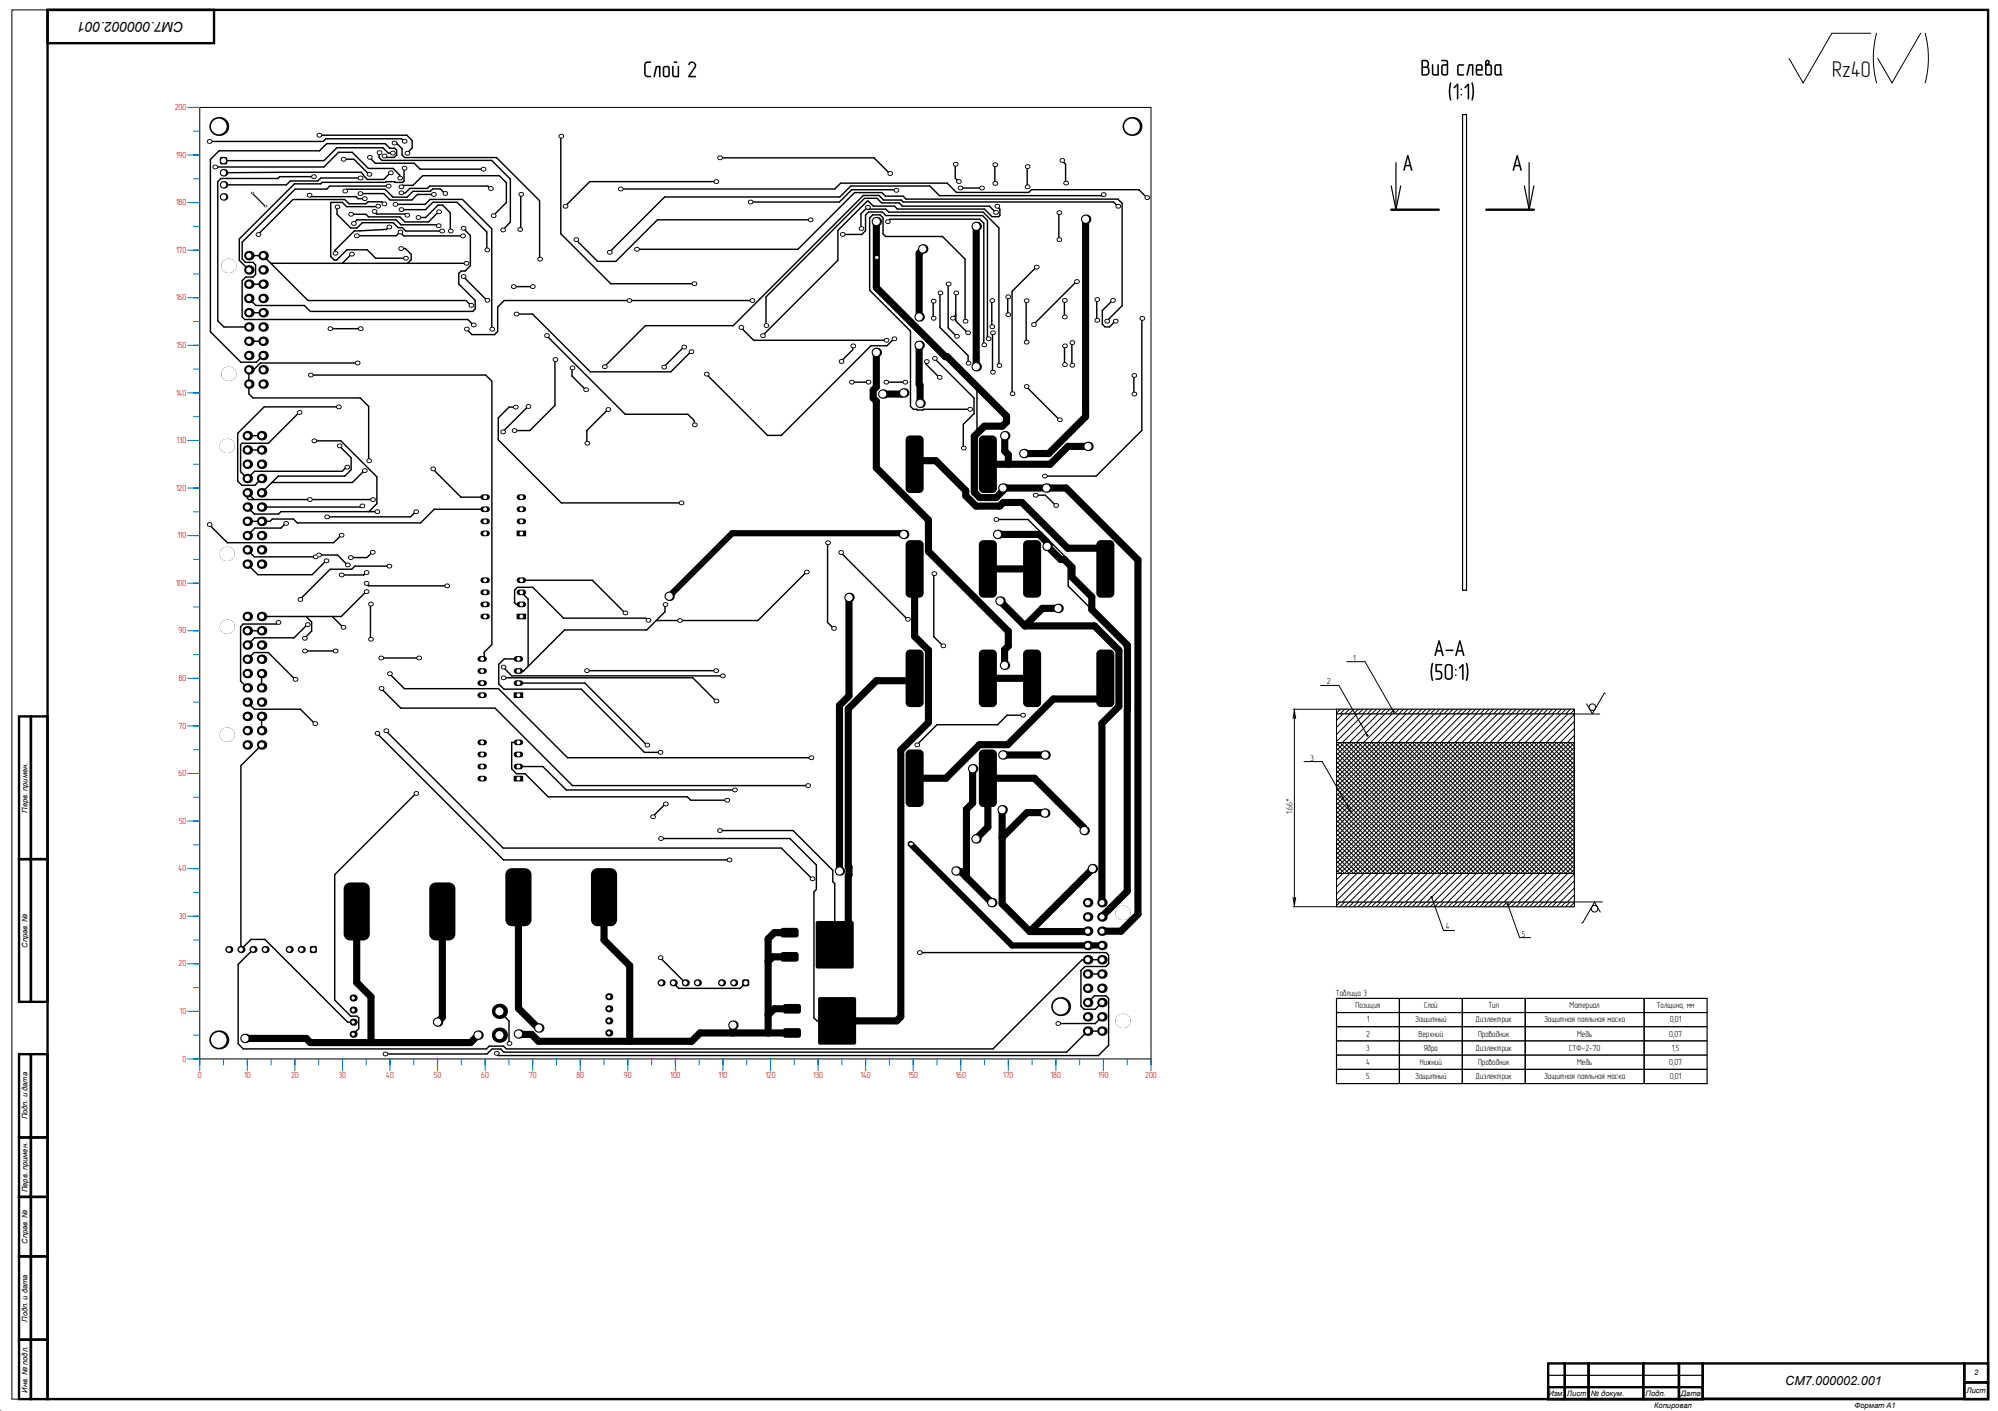
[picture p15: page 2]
Изм. Лист № докум.; Подп.; Дата; Лист2; Копировал; Формат А1; Позиция 12345; Слой; Защитный; Верхний; Ядро; Нижний; Тип; Диэлектрик; Проводник; Медь; СТФ-2-70; Толщина, мм; Таблица 3

Перв. примен. Справ. № Инв. № подл. Подп. и дата Справ. № Перв. примен. Подп. и дата

Материал
Защитная паяльная маска

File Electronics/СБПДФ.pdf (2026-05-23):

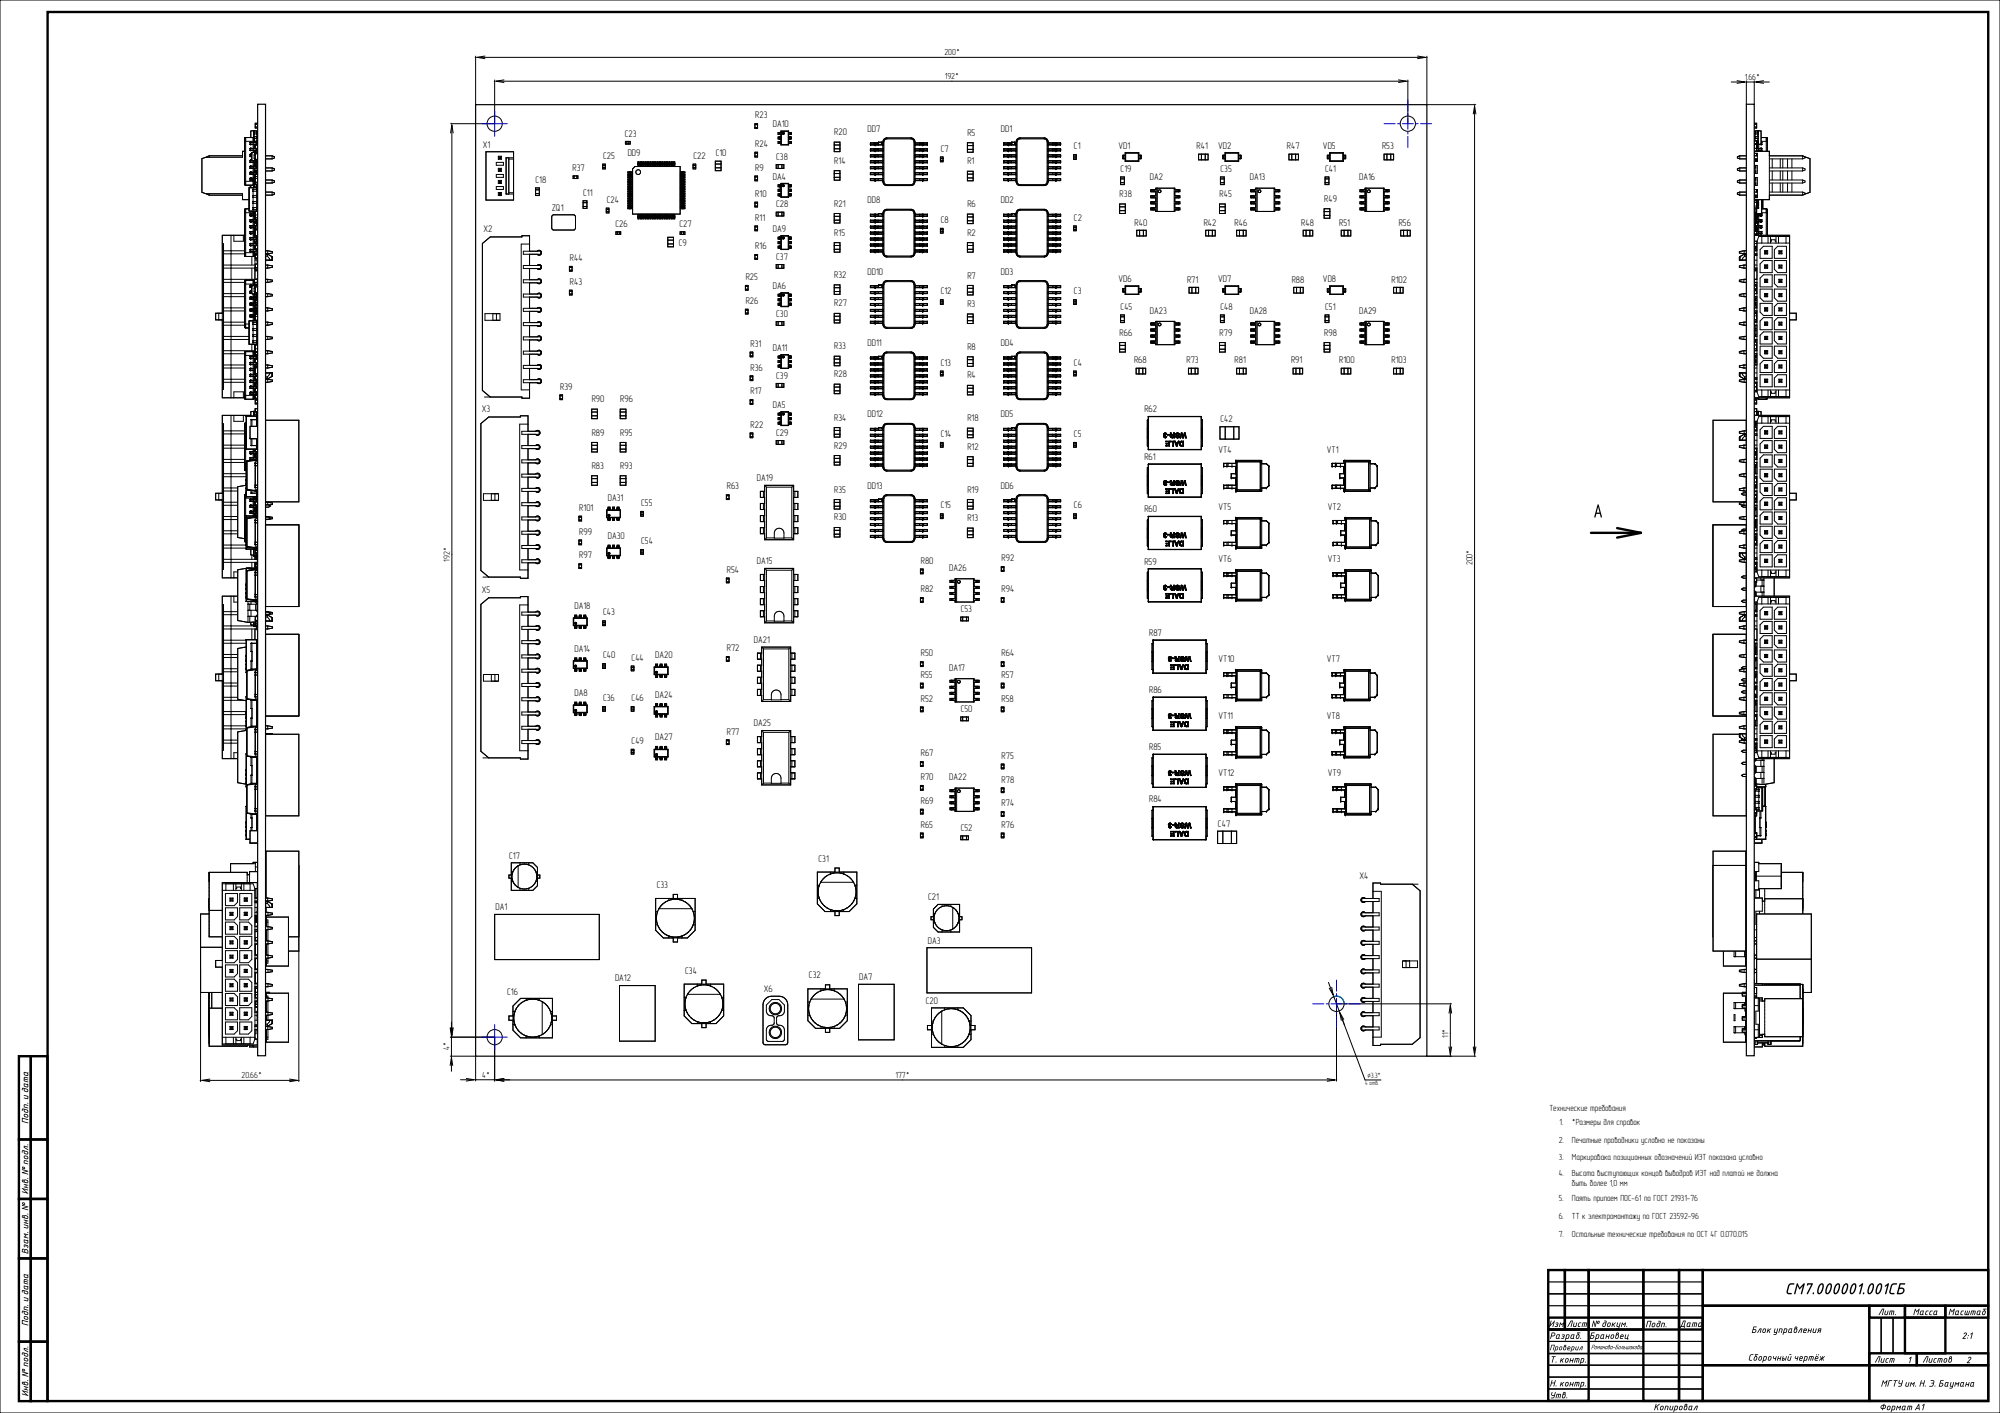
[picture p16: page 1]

2. Печатные проводники условно не показаны

3. Маркировака позиционных обозначений ИЭТ показана условно
Высота выступающих концов выводров ИЭТ над платой не должна
быть более 1,0 мм
5. Паять припоем ПОС-61 по ГОСТ 21931-76

6. ТТ к электромонтажу по ГОСТ 23592-96

7. Остальные технические требования по ОСТ 4Г 0.070.015

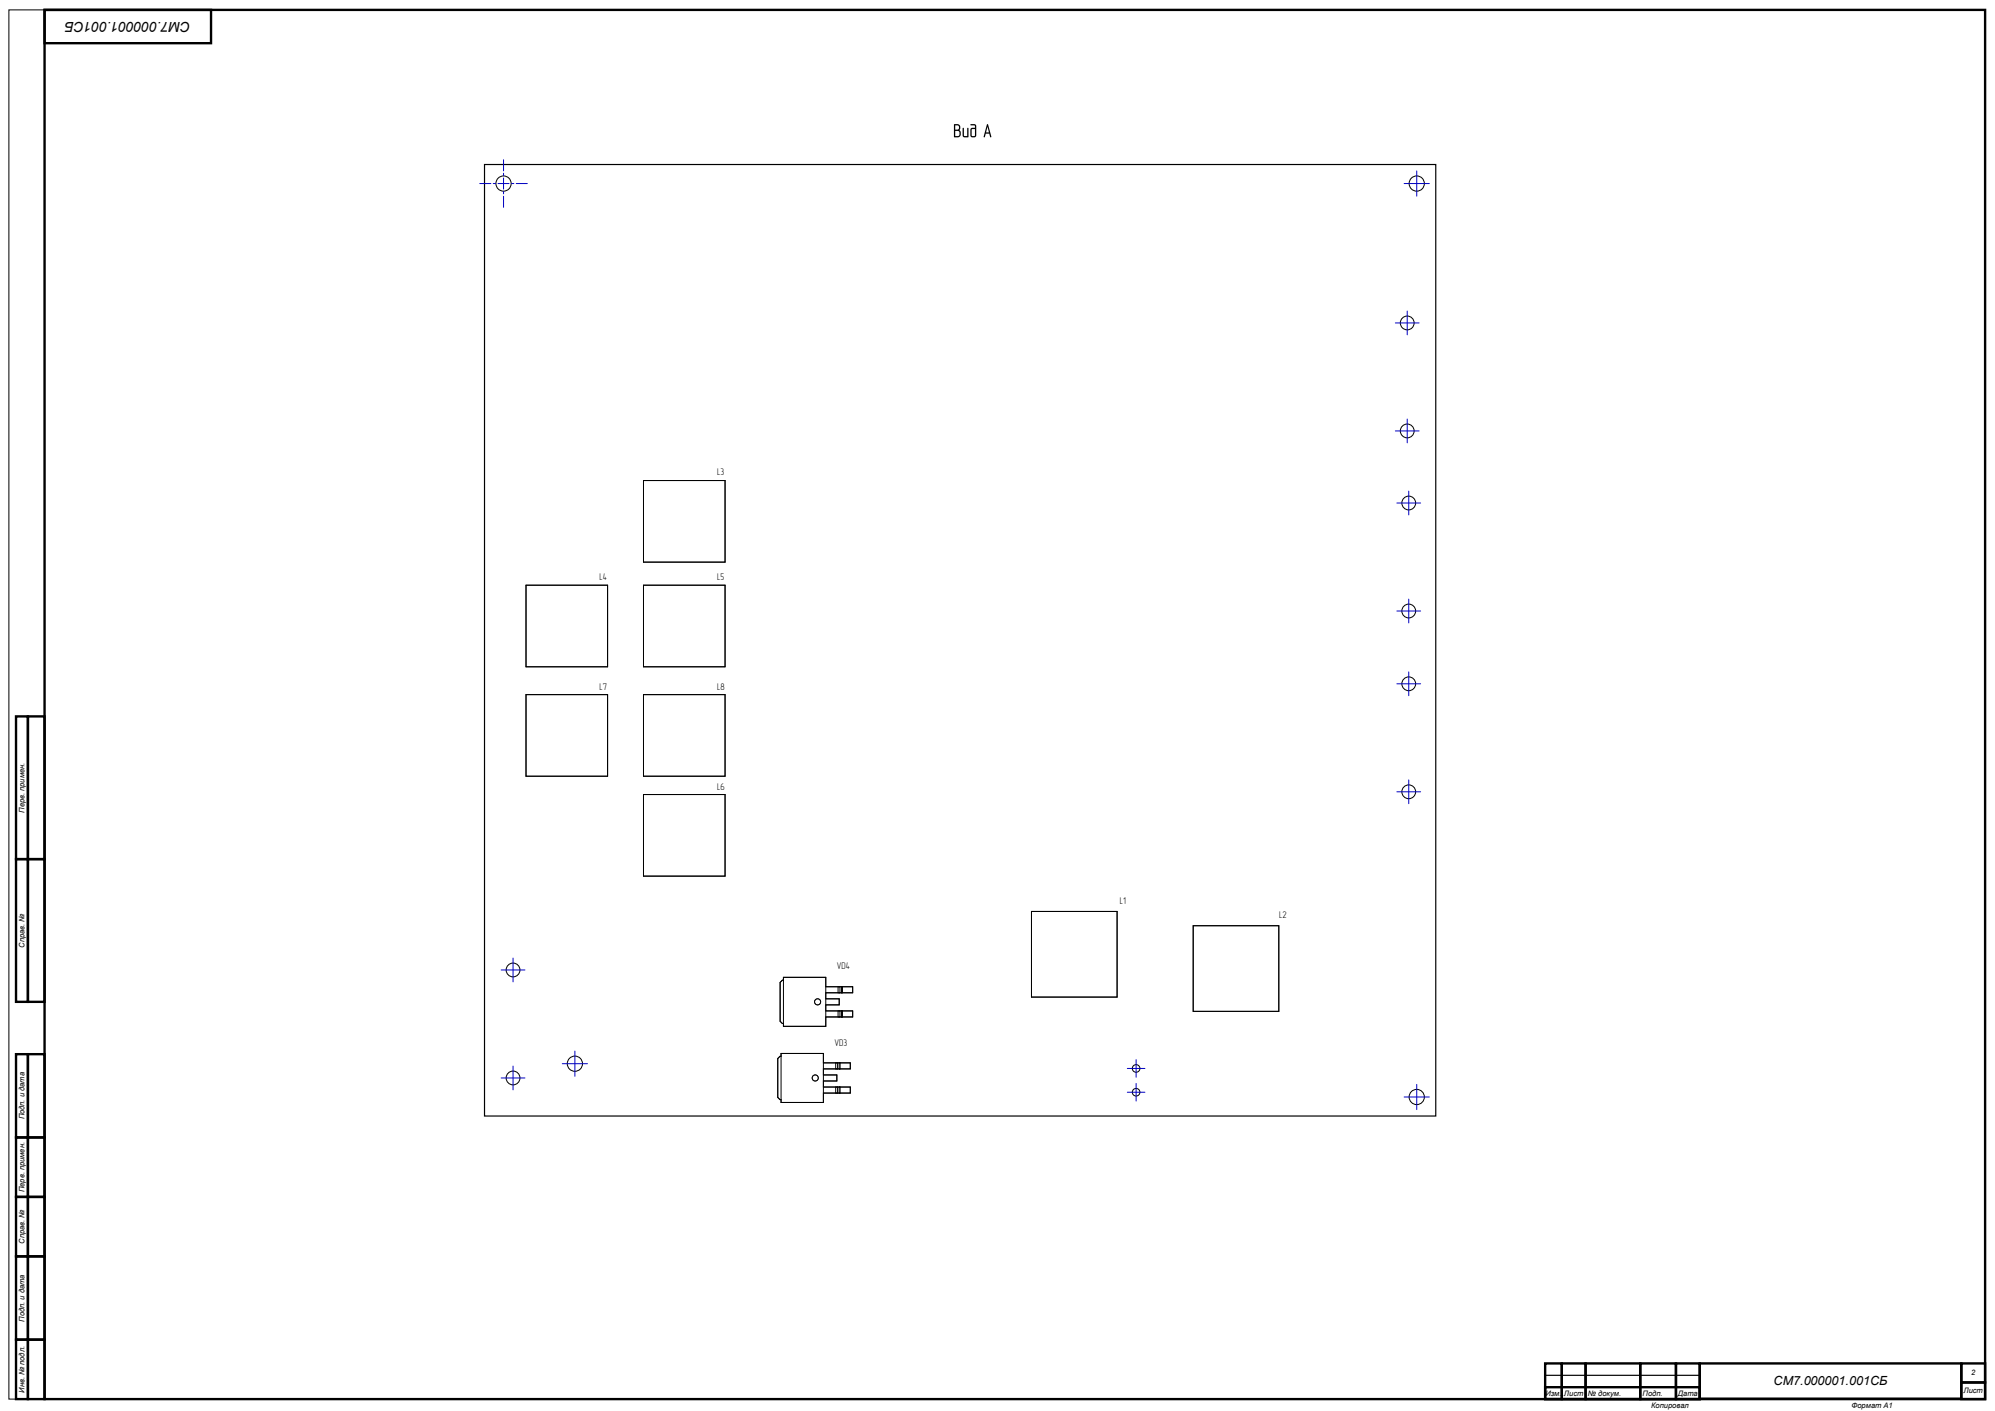
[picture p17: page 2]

Перв. примен. Справ. № Инв. № подл. Подп. и дата Справ. № Перв. примен. Подп. и дата

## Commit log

2026-01-06 Add: 3dmodels
    [sborkasb.STEP, sborkasbdet.STEP, sborkasp.STEP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]
2026-05-23 add: Electronics
    [PCBGOST.PcbDoc, main.SchDoc]
